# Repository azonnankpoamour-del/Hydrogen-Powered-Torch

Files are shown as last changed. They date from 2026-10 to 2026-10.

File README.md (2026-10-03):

# 🔥 Conception et réalisation d’un chalumeau à hydrogène alimenté par énergie solaire

Prototype du chalumeau

## 📌 Présentation du projet

Ce projet porte sur la **conception, le dimensionnement, la réalisation et l’expérimentation d’un chalumeau oxyhydrogène** utilisant un mélange gazeux HHO produit par **électrolyse de l’eau**.

Le système a été développé comme une alternative aux chalumeaux conventionnels utilisant des combustibles fossiles tels que l’acétylène.

L’objectif était de réaliser un prototype capable de produire son combustible à la demande et pouvant être utilisé pour des opérations de **chauffage, brasage, soudage et découpe de tôles fines**, tout en étant alimenté par une **source d’énergie solaire**.

Ce projet a été réalisé dans le cadre de mon projet de fin de formation en **Licence professionnelle – Équipements Motorisés** à l’ENSGEP / UNSTIM.

---

## 🎯 Objectifs

- Concevoir un système de chalumeau fonctionnant avec de l’hydrogène produit par électrolyse.
- Dimensionner le débit de gaz nécessaire au fonctionnement du chalumeau.
- Concevoir et intégrer un **générateur HHO de type Drycell**.
- Dimensionner l’alimentation électrique du système.
- Intégrer une alimentation photovoltaïque permettant d’améliorer l’autonomie énergétique du prototype.
- Concevoir mécaniquement l’ensemble du dispositif sous **SolidWorks**.
- Comparer différentes solutions électrolytiques.
- Réaliser et assembler le prototype.
- Effectuer des essais expérimentaux de production de gaz et de fonctionnement du chalumeau.
- Intégrer les dispositifs nécessaires à la sécurité du système.

---

## ⚙️ Principe de fonctionnement

Le fonctionnement du dispositif repose sur l’**électrolyse de l’eau**.

Sous l’action d’un courant électrique et en présence d’un électrolyte, l’eau est dissociée afin de produire du dihydrogène et du dioxygène :

**2 H₂O (l) → 2 H₂ (g) + O₂ (g)**

Le mélange gazeux produit par le générateur HHO est ensuite acheminé vers le chalumeau.

Le système comporte notamment un réservoir de solution électrolytique, une pompe de circulation, un générateur HHO-Drycell, un séparateur eau-gaz, les éléments de sécurité et le bec du chalumeau.

L’énergie nécessaire au fonctionnement du système est fournie par une batterie alimentée par un panneau photovoltaïque.

---

## 🧩 Architecture du système

Les principaux composants utilisés sont :

| Composant | Fonction |
|---|---|
| Générateur HHO – Drycell | Production du mélange gazeux HHO par électrolyse |
| Réservoir | Stockage de la solution électrolytique |
| Pompe de circulation | Circulation de la solution dans le système |
| Séparateur eau-gaz | Séparation du gaz produit et de la solution |
| Cartouche filtrante | Filtration de l’eau |
| Batterie LiFePO₄ 24 V – 10 Ah | Stockage de l’énergie électrique |
| Panneau photovoltaïque 355–375 W | Production d’énergie électrique |
| Régulateur solaire 40 A | Gestion de la charge de la batterie |
| Bec de chalumeau | Contrôle et orientation de la flamme |
| Tuyauterie et raccords | Circulation du gaz et de la solution |
| Dispositif anti-retour de flamme | Protection du circuit HHO |

---

## ☀️ Alimentation solaire

Schéma alimentation solaire

Le prototype a été conçu pour fonctionner avec une alimentation photovoltaïque.

### Caractéristiques principales

- **Panneau photovoltaïque : 355–375 W**
- **Batterie : LiFePO₄ 24 V – 10 Ah**
- **Énergie stockée : 240 Wh**
- **Régulateur de charge : 40 A**
- **Consommation théorique du Drycell : ≈ 120 W**
- **Autonomie théorique sur batterie : ≈ 2 h**

Cette architecture permet de réduire la dépendance à une alimentation électrique conventionnelle et apporte une autonomie énergétique au dispositif.

---

## 📐 Dimensionnement du débit d’hydrogène

Le dimensionnement a été réalisé pour permettre le travail sur une **tôle d’environ 0,8 mm d’épaisseur**.

En prenant comme référence un chalumeau oxyacétylénique :

- débit d’acétylène retenu : **250 mL/min**
- débit équivalent théorique d’hydrogène : **≈ 625 mL/min**
- plage de fonctionnement estimée : **600 à 750 mL/min de H₂**

Le dimensionnement théorique a donc retenu un débit cible d’environ :

**Q(H₂) = 625 mL/min**

---

## ⚡ Dimensionnement électrique

La production d’hydrogène a été dimensionnée à partir de la loi de Faraday.

Pour un débit cible de **625 mL/min**, le dimensionnement théorique conduit à un courant d’environ :

**I ≈ 60 A**

Avec une tension de cellule de l’ordre de **2 V**, la puissance théorique absorbée par le générateur est d’environ :

**P ≈ 120 W**

---

## 🧪 Étude expérimentale des électrolytes

Plusieurs solutions électrolytiques ont été étudiées expérimentalement afin d’analyser leur influence sur la production de gaz.

### Solutions testées

- Eau + bicarbonate de sodium (**NaHCO₃**)
- Eau de mer
- Eau + hydroxyde de potassium (**KOH**)

Le débit de gaz a été évalué expérimentalement par la **méthode du déplacement d’eau**.

### Résultats

| Solution | Débit expérimental |
|---|---:|
| NaHCO₃ | ≈ 1,0 L/min |
| Eau de mer | ≈ 0,7 L/min |
| KOH | ≈ 1,4 à 1,6 L/min |

Les essais ont montré que le **KOH présentait les meilleures performances** parmi les solutions étudiées.

L'étude de l'influence de la concentration a également montré un optimum expérimental autour de **6 %**, avec un débit pouvant atteindre environ **1,6 L/min avec le KOH**.

---

## 🖥️ Conception mécanique – CAO

### Générateur HHO

CAO générateur HHO

Le générateur HHO de type **Drycell** constitue l’un des éléments centraux du dispositif.

La conception mécanique a permis de définir l’organisation et l’intégration des différents composants nécessaires à la production et à la circulation du gaz.

### Assemblage du système

CAO système complet

L’ensemble du système a été modélisé sous **SolidWorks** afin d’étudier l’intégration des différents composants avant la réalisation du prototype.

Cette étape a notamment permis de travailler sur :

- la conception des pièces ;
- l’assemblage mécanique ;
- le positionnement des composants ;
- l’encombrement du système ;
- l’intégration du Drycell ;
- le passage des tuyauteries et connexions.

---

## 🔧 Réalisation du prototype

Prototype du chalumeau

Après la phase de conception et de dimensionnement, les différents composants ont été assemblés afin d'obtenir un prototype fonctionnel.

Le système comprend la chaîne :

**Énergie solaire → Batterie → Générateur HHO → Production HHO → Séparation / sécurité → Chalumeau → Flamme**

Le gaz est ainsi produit au fur et à mesure des besoins du système.

---

## 🔥 Essais et résultats

Les essais réalisés ont permis de valider le principe de fonctionnement du prototype.

### Principaux résultats

- Production effective de gaz HHO par électrolyse.
- Obtention d’une flamme stable au niveau du chalumeau.
- Débit expérimental supérieur au besoin théorique de **600–750 mL/min** avec certaines solutions électrolytiques.
- Meilleure performance obtenue avec le **KOH**.
- Débit maximal expérimental de l’ordre de **1,4 à 1,6 L/min** avec le KOH.
- Utilisation prévue pour le chauffage, le brasage, le soudage et le travail sur des tôles fines jusqu’à environ **0,8 mm**.
- Fonctionnement avec une alimentation photovoltaïque.

La littérature et le dimensionnement du projet situent la température d’une flamme oxyhydrogène à des valeurs pouvant approcher **2800 à 3300 °C** selon les conditions de fonctionnement.

> **Remarque :** la température exacte de la flamme du prototype n’a pas été mesurée expérimentalement, faute d’instrumentation adaptée. Elle ne doit donc pas être interprétée comme une température directement mesurée sur le prototype.

---

## 🛡️ Sécurité

La manipulation de l’hydrogène nécessite une attention particulière.

Plusieurs dispositions ont été prises en compte dans le projet :

- production du gaz en fonction des besoins ;
- limitation du stockage de gaz ;
- utilisation d’un dispositif anti-retour de flamme ;
- contrôle de l’étanchéité des raccords et tuyauteries ;
- vérification régulière de la cellule électrolytique ;
- éloignement des sources d’étincelles pendant les opérations de maintenance ;
- utilisation obligatoire des équipements de protection individuelle.

**EPI recommandés :**
- lunettes de protection ;
- gants de protection ;
- vêtements et équipements adaptés aux opérations de soudage.

---

## 💰 Étude économique

Le coût total estimé pour la fabrication du prototype est de :

### **637 000 XOF**

Ce montant comprend notamment :

- le générateur HHO ;
- les accessoires de circulation d’eau et de gaz ;
- le câblage ;
- le panneau photovoltaïque ;
- le régulateur solaire ;
- la batterie LiFePO₄ ;
- le bec du chalumeau ;
- le transport et les accessoires nécessaires au montage.

L’utilisation de l’énergie solaire permet par ailleurs de réduire le coût électrique associé au fonctionnement du système.

---

## 🚀 Perspectives d’amélioration

Plusieurs améliorations ont été identifiées :

- optimisation du rendement du générateur HHO ;
- optimisation de la concentration de l’électrolyte ;
- amélioration de la conception des électrodes ;
- instrumentation du système pour mesurer précisément température, pression et débit ;
- intégration de capteurs de température et de gaz ;
- automatisation de la régulation avec un microcontrôleur ou un automate ;
- mise en place d’une protection contre la surchauffe et les surtensions ;
- poursuite des recherches sur l’utilisation de l’eau de mer dans un contexte maritime ;
- amélioration de la compacité et de la portabilité du dispositif.

---

## 🧠 Compétences mobilisées

Ce projet m’a permis de mettre en œuvre des compétences multidisciplinaires en :

**Conception mécanique**
- CAO sous SolidWorks
- conception de pièces et assemblages
- intégration mécanique
- prototypage

**Dimensionnement**
- calcul énergétique
- dimensionnement électrique
- dimensionnement d’un générateur HHO
- dimensionnement d’une alimentation photovoltaïque

**Expérimentation**
- électrolyse de l’eau
- étude comparative d’électrolytes
- mesure de débit par déplacement d’eau
- analyse et interprétation de résultats expérimentaux

**Énergie**
- hydrogène
- énergie solaire photovoltaïque
- batterie LiFePO₄
- gestion énergétique

**Gestion de projet**
- étude du besoin
- conception
- dimensionnement
- réalisation
- essais
- analyse économique
- amélioration continue

---

## 📄 Documentation

Pour aller plus loin, la documentation complète du projet est disponible directement dans ce dépôt :

- 📘 [Consulter le rapport complet du projet](Rapport-Projet-Chalumeau-Hydrogene.pdf)
- 📗 [Consulter le manuel d'utilisation](Manuel-Utilisation-Chalumeau-Hydrogene.pdf)

Le rapport présente notamment le **dimensionnement**, la **conception mécanique**, les **essais expérimentaux**, l'**étude énergétique** et l'**étude économique** du prototype.

Le manuel présente le **principe de fonctionnement**, les différents composants, la **mise en service**, les consignes de **sécurité**, l'entretien et le dépannage.

Ces documents présentent le dimensionnement, la conception, les résultats expérimentaux, les procédures d’utilisation ainsi que les recommandations de sécurité.

## 🧩 Fichiers CAO

Le modèle 3D du générateur HHO de type **Drycell** est disponible dans deux formats :

- ⚙️ [Fichier source SolidWorks (.SLDPRT)](Generateur-HHO-Drycell.SLDPRT)
- 🧊 [Modèle 3D STL (.STL)](Generateur-HHO-Drycell.STL)

La modélisation CAO a été réalisée sous **SolidWorks** dans le cadre de la conception du système de production HHO.

---

## 👤 Auteur

**Amour Tamègnon AZONNANKPO**

Projet de fin de formation – Licence professionnelle  
**Génie Mécanique-Équipements Motorisés**

École Nationale Supérieure de Génie Énergétique et Procédés (**ENSGEP**)  
Université Nationale des Sciences, Technologies, Ingénierie et Mathématiques (**UNSTIM**)

Année académique : **2024–2025**

---

## ⚠️ Avertissement

Ce dépôt présente un projet académique et expérimental.

L’hydrogène et les mélanges hydrogène/oxygène présentent des risques importants d’incendie et d’explosion. Les informations contenues dans ce dépôt sont fournies à des fins de présentation technique et pédagogique et ne constituent pas des instructions permettant de reproduire le dispositif sans équipements, procédures de sécurité et encadrement appropriés.

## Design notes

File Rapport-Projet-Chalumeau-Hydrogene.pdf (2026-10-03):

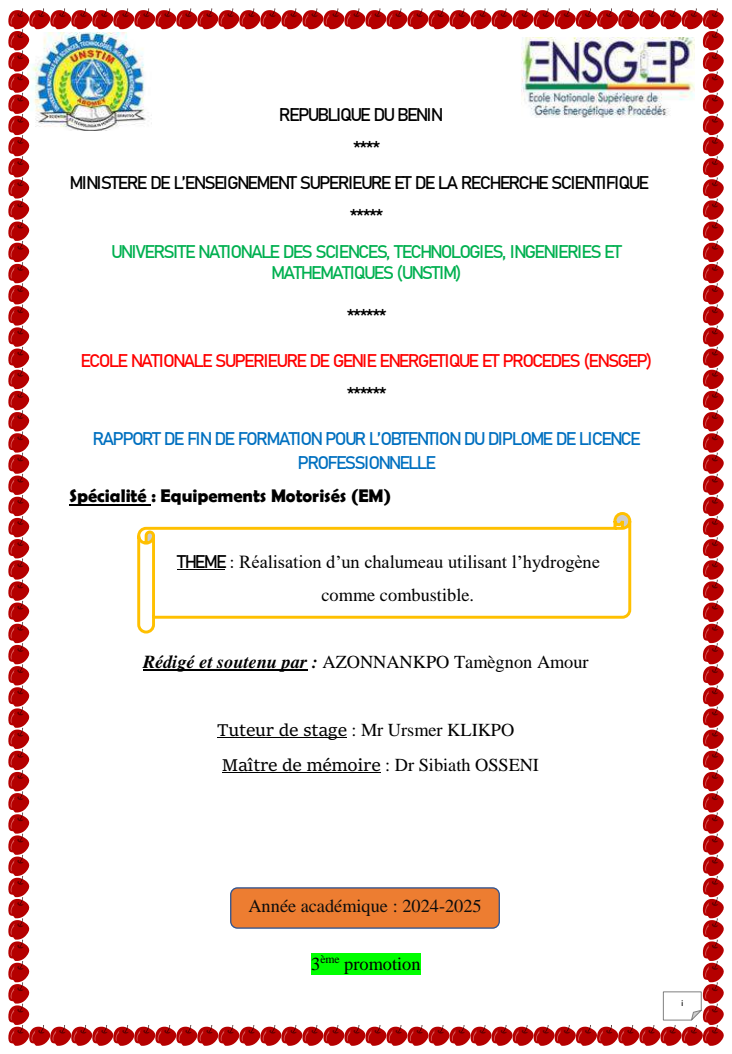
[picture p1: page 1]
Année académique : 2024-2025; MATHEMATIQUES (UNSTIM); PROFESSIONNELLE; comme combustible.; ème promotion

REPUBLIQUE DU BENIN

MINISTERE DE L’ENSEIGNEMENT SUPERIEURE ET DE LA RECHERCHE SCIENTIFIQUE

UNIVERSITE NATIONALE DES SCIENCES, TECHNOLOGIES, INGENIERIES ET

ECOLE NATIONALE SUPERIEURE DE GENIE ENERGETIQUE ET PROCEDES (ENSGEP)

RAPPORT DE FIN DE FORMATION POUR L’OBTENTION DU DIPLOME DE LICENCE

Spécialité : Equipements Motorisés (EM)

THEME : Réalisation d’un chalumeau utilisant l’hydrogène

Rédigé et soutenu par : AZONNANKPO Tamègnon Amour

Tuteur de stage : Mr Ursmer KLIKPO

Maître de mémoire : Dr Sibiath OSSENI

ii
Réalisation d’un chalumeau utilisant l’hydrogène comme combustible

## FICHE DE CERTIFICATION D’ENCADREMENT

Je soussigné, Sibiath OSSENI, Docteur en Génie Energétique et enseignante à l’Université Nationale des Sciences, Technologies ; Ingénieries et Mathématiques d’Abomey, certifie que ce travail effectué par AZONNANKPO Tamègnon Amour est original et n’a jamais été présenté pour l’obtention de quelconque grade universitaire que ce soit.

Date : |

Signature

iii

## DEDICACE

Je dédie ce modeste travail :

À Dieu Tout-Puissant, qui nous a protégés jusqu’à aujourd’hui ;
À mes chers parents, pour leur amour, leur soutien indéfectible et les nombreux sacrifices qui m'ont permis de poursuivre mes études ;
À mes enseignants et mentors, pour leur dévouement, leur patience et les précieuses connaissances qu'ils m'ont transmises tout au long de mon parcours académique ;
À mes camarades, pour leur esprit de collaboration, leurs encouragements et leur amitié tout au long de cette aventure ;
Enfin, à tous ceux qui croient en l'importance des Equipements Motorisés pour le développement technologique et durable.

iv

## REMERCIEMENTS

En premier lieu, je rends gloire et honneur à Dieu le Père Tout-Puissant pour sa grâce qui m’a accompagné tout au long de ma vie. Cette œuvre est le fruit de l’effort matériel, physique et intellectuel de plusieurs personnes. Au terme de son édification, qu’il me soit permis d’exprimer mes gratitudes et mes sincères remerciements à tous ceux qui, d’une façon ou d’une autre, ont contribué à la réussite et à la rédaction de ce mémoire.

Ainsi, mes sincères remerciements vont à l’endroit de :

Pr Antonin KANFON, Directeur actuel de l’ENSGEP, pour son accompagnement, son soutien moral, ses multiples conseils, ses orientations et sa disponibilité malgré ses occupations professionnelles et personnelles ; Dr Jean Louis FANNOU, ancien directeur de l’ENSGEP pour tout le travail effectué,
Dr Sibiath OSSENI, pour son encadrement sans faille et ses précieux conseils ; Dr Miguel ADANKPO, pour son encadrement et ses précieux conseils sur mon projet de RCHC
Tous les enseignants et membres de l’administration de l’ENSGEP, pour leurs enseignements enrichissants, les efforts qu’ils ont déployés afin de m’assurer une formation actualisée et pour m’avoir permis de travailler dans de bonnes conditions;
M. Ursmer KLIKPO mon tuteur de stage, Lieutenant mécanicien de 1ère classe et Chef du Service Engins Flottants (SEF), pour son accueil chaleureux, son suivi attentif, ses enseignements, ses précieux conseils, ses recommandations et sa disponibilité à la salle machine ;
Tous les chefs mécaniciens (officiers et graisseurs) des remorqueurs et des pilotines, pour tous les travaux effectués ensemble, l’apprentissage et leurs précieux conseils ;
Tous les patrons de vedette, tous les capitaines de remorqueurs et tous les commandants pilotes, pour leur disponibilité, leurs conseils et tout le travail effectué ensemble ;
À tous les équipages du PAC, ce fut un honneur de travailler ensemble ;; Vous, membres du jury, qui avez accepté de prendre le temps et la responsabilité d’apprécier ce travail malgré vos multiples occupations ;
À tous mes aînés qui m’ont aidé dans la rédaction de ce document.

v

## TABLE DES MATIERES

2.1.1 MESURES DE SECURITES A BORD DE LA PILOTINE ET DES

vi

CHAPITRE 3 : REALISATION D’UN CHALUMEAU UTILISANT

3.1 | GENERALITES SUR LA REALISATION D’UN CHALUMEAU
3.1.3 | UTILISATION D’UN CHALUMEAU A HYDROGENE PAR

### 3.1.3.1 AVANTAGES ET INCONVENIENTS D’UN CHALUMEAU A

3.1.4 APPLICATION DU CHALUMEAU A HYDROGENE SUR LES NAVIRES POUR LES TRAVAUX EN MER (CAS DES REMORQUEURS DU

3.2.1 | LES PRINCIPAUX ELEMENTS DU CHALUMEAU OXYHYDRIQUE
| 35
3.2.2 | DIMENSIONNEMENT DU CHALUMEAU OXYHYDROGENE....... 39
3.2.4 | ETAPES DE LA REALISATION DU CHALUMEAU A HYDROGENE
| 43

vii

## LISTE DES SIGLES ET ABREVIATIONS

ENSGEP | Ecole Nationale Supérieure de Génie Energétique et Procédés
EM | Equipements Motorisés
SGE | Secrétaire Générale d’Entité de l’ENSGEP
UNSTIM | Université Nationale des Sciences Technologies, Ingénierie et Mathématiques
RCHC | Réalisation d’un Chalumeau utilisant l’hydrogène comme combustible
PAC | Port Autonome de Cotonou
GE | Groupe Electrogène
MP | Moteur Propulseur
Td | Tribord
Bd | Bâbord
ml | Millilitre
mm | Millimètre
g | gramme
J | Joule
cm | Centimètre
°C | Degré Celsius
MJ | Mégajoule
KJ | Kilojoule
Wh | Wattheure
A | Ampère
V | Volt
∆ | Delta T

viii

## LISTE DES TABLEAUX

Tableau 5: Récapitulatif des avantages et inconvénients des chalumeaux oxhydriques

Tableau 13 : Détails sur le système d’alimentation du chalumeau à hydrogène…64

ix

## LISTE DES FIGURES

Figure 23 : Drycell | 47.

Figure 26 : Conception assistée par ordinateur du chalumeau à hydrogène (SolidWorks)..55.

x

## RESUME

L’hydrogène s’impose aujourd’hui comme une solution énergétique propre, sûre et efficace pour remplacer les combustibles fossiles dans les applications industrielles.

A cet effet, l’étude a porté sur la réalisation d’un chalumeau fonctionnant à l’hydrogène et utilisant une source d’énergie solaire, une alternative aux chalumeaux classiques à butane ou à acétylène, plus polluants et dangereux.

Dans ce projet, il a d’abord été nécessaire de concevoir, dimensionner puis assembler un chalumeau oxyhydrogène fonctionnel. Le principe repose sur l’électrolyse de l’eau, permettant de générer un mélange gazeux d’hydrogène et d’oxygène (HHO) servant de combustible à une flamme maîtrisée. L’ensemble de l’étude a intégré une sélection des matériaux, la mise en place d’un système de sécurité adapté à l’hydrogène, ainsi que plusieurs essais de performance et de fiabilité.

Les résultats expérimentaux ont démontré l’efficacité thermique du chalumeau, avec une température de flamme atteignant jusqu’à 3300 °C, comparable à celle de l’oxycoupage classique. Le système a également présenté un fonctionnement stable et sécurisé avec un débit d’hydrogène assez élevé obtenu grâce à une électrolyse optimisée, permettant une alimentation continue de la flamme.

Le coût total du projet est estimé à 637 000 XOF, hors main-d’œuvre. Ce montant couvre l’achat des matériels et l’acquisition des dispositifs techniques nécessaires au montage.

Ce chalumeau constitue une avancée technologique viable, conjuguant sécurité, performance, autonomie énergétique et réduction des impacts environnementaux.

Mots-clés : hydrogène, chalumeau, combustion propre, électrolyse, énergie renouvelable, soudage

xi

ABSTRACT

Hydrogen is emerging today as a clean, safe, and efficient energy solution to replace fossil fuels in industrial applications.

This study focused on the development of a hydrogen-powered torch using a solar energy source, offering an alternative to conventional butane or acetylene torches, which are more polluting and hazardous.

The project involved designing, sizing, and assembling a functional oxyhydrogen torch. The operating principle is based on water electrolysis, which generates a gaseous mixture of hydrogen and oxygen (HHO) used as fuel for a controlled flame. The study included material selection, the implementation of a safety system adapted to hydrogen, and several performance and reliability tests.

Experimental results demonstrated the thermal efficiency of the torch, with a flame temperature reaching up to 3300 °C, comparable to that of conventional oxy-cutting systems. The system also operated in a stable and safe manner, with a relatively high hydrogen flow rate achieved through optimized electrolysis, enabling continuous flame supply.

The total cost of the project is estimated at 637,000 XOF, excluding labor. This amount covers the purchase of materials and the acquisition of the technical components required for assembly.

This torch represents a viable technological advancement, combining safety, performance, energy autonomy, and reduced environmental impact.

Keywords: hydrogen, torch, clean combustion, electrolysis, renewable energy, welding

1

INTRODUCTION GENERALE

L’énergie est un élément déterminant et indispensable pour l’économie d’un pays. Elle est directement liée à son développement, cela est valable pour les pays développés (industrialisés) que pour les pays émergents.

Les combustibles d’origine fossile contribuent massivement au réchauffement climatique de la terre par "effet de serre" dû au dégagement du dioxyde de carbone par leur combustion dans l'atmosphère. La prise de conscience environnementale à travers les accords internationaux tel que l’accord de Kyoto a poussé les pays industrialisés à réduire leur rejet de gaz à effets de serre : l'Allemagne est parvenue à elle seule à réduire ses rejets à 50 millions de tonnes de CO2. [1]

L’hydrogène est l’une des solutions énergétiques qui pourra répondre aux besoins actuels. Bien qu'on le trouve en abondance dans l'univers, mais combiné avec d'autres atomes : cas notamment de l'eau, du pétrole ou du gaz naturel. L’hydrogène est considéré comme un vecteur énergétique très intéressant produit essentiellement par électrolyse. Il est utilisé essentiellement dans la chimie, le raffinage ou l’industrie. A l’heure des préoccupations environnementales, l’hydrogène pourrait bien, jouer un rôle prépondérant dans le paysage énergétique futur. [2]

Le travail présenté dans ce mémoire est relatif à la « RÉALISATION D’UN CHALUMEAU UTILISANT L’HYDROGÈNE COMME COMBUSTIBLE », une solution innovante, plus sûre, plus écologique et mieux adaptée aux besoins modernes de soudage et de réparation, notamment dans les industries et à bord des vedettes et remorqueurs où la sécurité est une exigence capitale.

Ce travail sera structuré en trois grands chapitres :

Le premier chapitre présentera notre cadre de formation (ENSGEP/ABOMEY) ainsi que la structure d’accueil pour notre stage.
Le deuxième chapitre décrira le déroulement du stage ainsi que les différents travaux pratiques réalisés.
Le troisième chapitre sera consacré à l’étude approfondie du thème
« RÉALISATION D’UN CHALUMEAU UTILISANT L’HYDROGÈNE

COMME COMBUSTIBLE ».

2

## CHAPITRE 1 : CADRE INSTITUTIONNEL DU STAGE

3

INTRODUCTION

Dans le cadre de la formation pratique des étudiants, l’École Nationale Supérieure de Génie Énergétique et Procédés organise chaque année des stages en entreprise. Ces stages permettent aux étudiants d'appliquer sur le terrain les connaissances théoriques acquises durant leur cursus. C’est ainsi que j'ai effectué mon stage de fin de formation au Port Autonome de Cotonou (PAC), dans le but de renforcer mes compétences pratiques en maintenance marine et d’approfondir ma compréhension des réalités professionnelles.

### 1.1 PRESENTATION DU CADRE DE FORMATION 1.1.1 HISTORIQUE

L'École Nationale Supérieure de Génie Énergétique et Procédés (ENSGEP) constitue une composante clé de l'Université Nationale des Sciences, Technologies, Ingénierie et
Mathématiques | (UNSTIM) | d'Abomey. | Créée | par | l'Arrêté | Ministériel | N°
207/MESRS/DC/SGM/DGES/DAF/R-UNSTIM/CCJ/SA 027SGG18 en date du 18 avril 2018, elle place l'innovation et l'excellence au cœur de son contrat pluriannuel, renforçant ainsi son attractivité. L'ENSGEP se donne pour mission de former des ingénieurs et techniciens spécialisés dans les domaines des sciences et des technologies, avec un accent particulier sur le génie énergétique et les procédés, la réfrigération et la climatisation, ainsi que les équipements motorisés.

Nos ingénieurs, experts en solutions techniques dans les secteurs de l'industrie et de l’énergie, maîtrisent la conception, l'étude, le dimensionnement et la mise en œuvre des unités de production adaptées à une diversité d'activités. Quant à nos techniciens, leurs compétences leur permettent d'installer et de garantir la maintenance efficace des systèmes de réfrigération, de climatisation et des équipements motorisés. Depuis son ouverture à l'année académique 2018-2019, l'ENSGEP s'engage à assurer :

- Des formations de pointe, conduisant principalement aux diplômes d’ingénieur de conception (BAC+5) en sciences et technologies appliquées à l’énergétique et aux procédés industriels, ainsi qu’aux diplômes de licence professionnelle (BAC+3) dans les domaines du froid et de la climatisation, et des équipements motorisés.
- La recherche scientifique et technique, visant à promouvoir l'innovation technologique dans les sciences et technologies de l’énergétique et des procédés industriels.
- La formation continue, destinée à répondre aux besoins des personnels des entreprises publiques et privées, favorisant leur montée en compétences dans les domaines spécifiques sollicités.

4

### 1.1.2 DEBOUCHES POUR LES FORMATIONS A l’ENSGEP

L’ENSGEP présente trois (03) formations :

Un cycle d’ingénieur en Génie Energétique et Procédés

Débouchés : Ingénieur industriel, Chef d’usine, Ingénieur Bureau d’étude, Ingénieur conseil et commercial près des fabricants des équipements énergétiques, Ingénieur en énergies renouvelables, etc.
Un cycle de Licence professionnelle en Équipements Motorisés

Débouchés : Technicien en installation, mise en service et maintenance des

Équipements Motorisés, Électromécanicien, Technicien en Mécanique automobile, Technicien en installation et Maintenance des appareils électroménagers, Technicien en installation et Maintenance des engins de travaux publics, Technicien en installation et Maintenance des groupes électrogènes, s’installer à son propre compte.

Un cycle de Licence professionnelle en Froid et Climatisation

Débouchés : Technicien en installation, mise en service et maintenance d’installations frigorifiques près de PME et Institutions, s’installer à son propre compte les prestations de service en froid et climatisation.

### 1.1.3 CONDITIONS D’ACCES A l’ENSGEP

L’accès au cycle d’ingénieur de l’ENSGEP est réservé aux étudiants ayant fini les classes préparatoires à l’Institut Nationale des Classes Préparatoires aux Etudes d’Ingénieur (INSPEI) ou sur un test d’entrée pour ceux qui ont fait les deux ans d’année préparatoire scientifique ou sur un test d’entrée pour ceux qui ont la licence professionnelle en Energie renouvelable, Génie mécanique et productique, Génie industriel et maintenance, Energie renouvelable et maintenance des systèmes énergétiques, Physique ou tout autre diplôme équivalent.

L’accès au cycle de licence professionnelle se fait sur le classement des nouveaux bacheliers des séries C, D, E, DT/FC et DEAT par le ministère (sélection à titre de boursiers, à titre partiellement payant et à titre entièrement payant) et sur étude de dossiers (à titre entièrement payant uniquement) des anciens bacheliers des séries C, D, E, DT/FC et DEAT. L’école dispose d’un laboratoire pluridisciplinaire pour les travaux pratiques de ses étudiants et collabore avec plusieurs laboratoires et entreprises tant publics que privés afin de renforcer la professionnalisation de ses offres de formation.

5

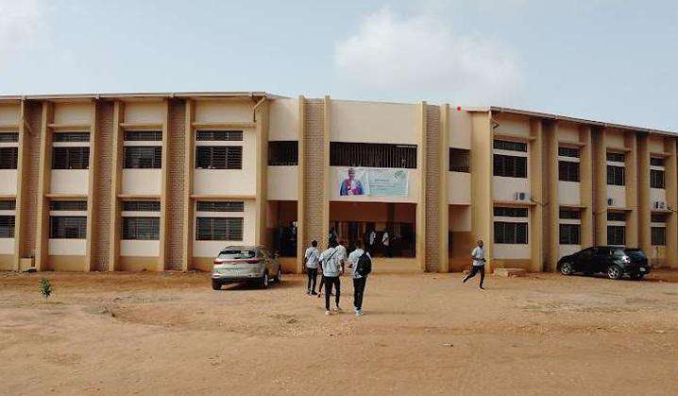
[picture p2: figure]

Figure 1 : Photographie montrant la devanture du site provisoire de l’ENSGEP [3]

### 1.1.4 LOCALISATION

L’ENSGEP est situé dans la ville d’Abomey dans le département du Zou, au Bénin. Précisément à Sogbo-Aliho en face l’école Shino Béninoise de la ville. Le site est à gauche proche de la Route Inter Etat quittant le carrefour Sogbo-Aliho pour l’Ecole Nationale des Instituteurs (ENI) d’Abomey comme l’indique la figure 2

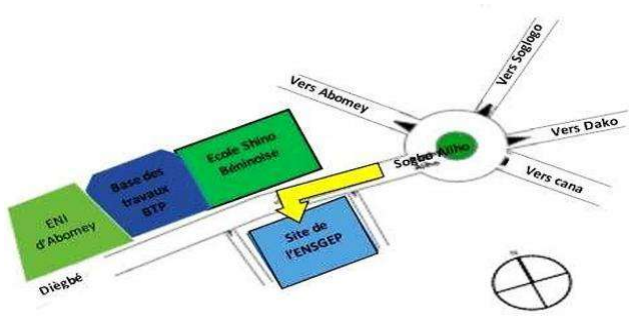
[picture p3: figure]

Figure 2 : Plan de la situation géographique de l’ENSGEP [4]

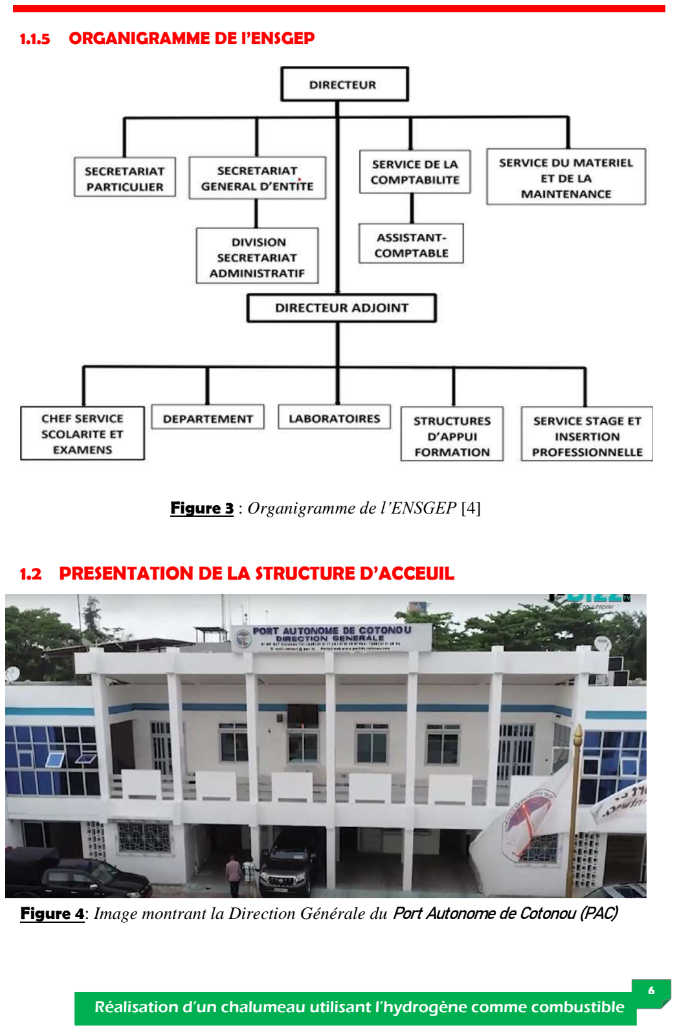
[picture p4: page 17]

6

### 1.1.5 ORGANIGRAMME DE l’ENSGEP

Figure 3 : Organigramme de l’ENSGEP [4]

## 1.2 PRESENTATION DE LA STRUCTURE D’ACCEUIL

Figure 4: Image montrant la Direction Générale du Port Autonome de Cotonou (PAC)

7

### 1.2.1 HISTORIQUE ET ORGANISATION DE L’ENTREPRISE

### - Historique du Port Autonome de Cotonou (PAC)

L’embarquement et le débarquement des marchandises s’effectuaient en deux points du littoral du Bénin (Grand-Popo à l’embouchure du Mono et Ouidah, ancien port de la traite des esclaves) par transbordement des pirogues qui assuraient la liaison entre les navires mouillants en rades foraines et le rivage avant la naissance du port autonome de Cotonou (Janin, 1964). Ainsi, la ville de Cotonou est dotée d’un wharf (passe raine métallique). La sécurité des marchandises et des personnes et la rapidité dans l’exécution des opérations a permis au site de Cotonou de supplanter celui de Grand-Popo et de Ouidah et de devenir le principal port du Dahomey. La réalisation donc d’un port moderne en eau profonde rend concrète la supériorité de Cotonou (Janin, 1964). Ce port est né pour faire face aux concurrences avec les ports du Sénégal et de la Cote d’Ivoire. Le port de Cotonou depuis ce temps est le véritable atout de développement économique car il représente 75% du trafic dahoméen (Janin, 1964). [5]

Le port représente aujourd’hui 50% de la richesse nationale du pays et fait 90% des échanges avec l’étranger d’où il est le véritable poumon de l’économie béninoise (INSAE, 2011). Il fait du commerce entre les autres pays du monde notamment l’Europe, l’Amérique Nord comme du Sud et l’Asie (PAC, 2013 et Messan, 2014). Ainsi le port de Cotonou est le port relai de la première puissance économique africaine qu’est le Nigéria et le port de transit du Niger (Messan, 2014) d’où la richesse nationale du Bénin (INSAE, 2011). [5]

### - Situation géographique du port autonome de Cotonou

Situé à la latitude 6°11’22’’ Nord, le Port de Cotonou est implanté sur une côte sablonneuse en bordure sud de la ville de Cotonou, capitale économique de la République du Bénin. Port en eau profonde à accumulation de sable, il a pour grand avantage de fournir aux navires un plan d’eau abrité, pouvant leur permettre d’effectuer des opérations commerciales et de ravitaillement dans d’excellentes conditions. Sa position géographique lui offre un travail indéniable. Cette disposition contribue à l’efficacité du Port et à la rapidité d’escale des navires. En effet, le Port Autonome de Cotonou est le débouché à la mer le plus proche, le couloir d’accès le plus rapide, le moins accidenté pour desservir l’Est des pays sans littoral tels que le Mali, le Burkina-Faso, le Niger et le Tchad.

Dans la sous- région, le Port de Cotonou est sensiblement à égale distance des ports de Lagos (Nigeria) 115Km et de Lomé (Togo) 135Km. Le port de Cotonou est le port relai et de transbordement le plus rapide vers le Nigéria. [5]

8

### 1.2.1.1 ORGANIGRAMME DU PAC

Figure 5 : Schéma montrant l’Organigramme du PAC [6]

9

### 1.2.2 LA FLOTTE DU PAC

- Service pilotine

Cette section est responsable du transport du pilote. La pilotine se rend jusqu’à la bouée d’atterrissage pour déposer le pilote à bord du navire étranger lors de son entrée. En cas de sortie, la pilotine récupère le pilote après qu’il a assisté le commandant à rejoindre la voie de départ. Cette section dispose de deux pilotines : AGBONNON et EMERGENCE.

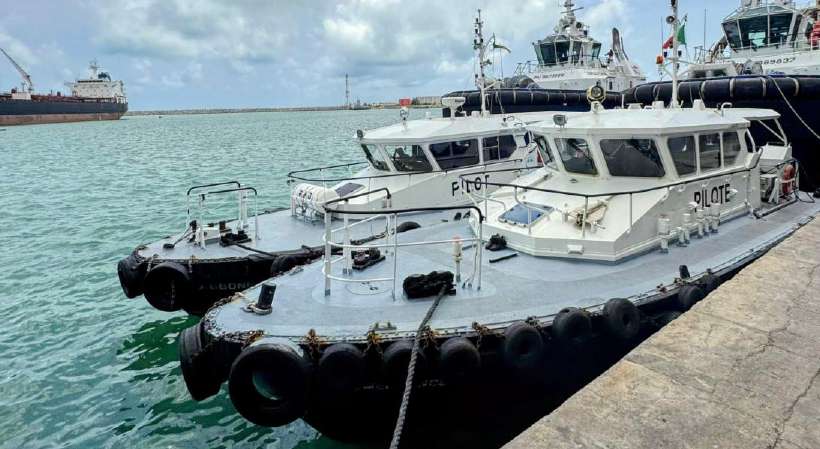
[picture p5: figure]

Figure 6 : Image montrant les deux pilotines EMERGENCE ET AGBONON

Tableau 1 : Caractéristiques des pilotines [6]

Engins | Année de construction | Longueur(m) | Largeur(m) | Tirant(m) | Puissance moteur
EMERGENCE | 2007 | 15,25 | 04,80 | 1,255 | 720Kw
AGBONNON | 2018 | 15,21 | 04,47 | 2,18 | 640Kw
- Service remorquage

La remorque est un ensemble d’éléments qui permettent de tracter un navire. Elle sert à guider, tirer, pousser les gros bateaux entrant et sortant du port. La station de remorquage du port autonome de Cotonou est équipée de trois remorqueurs à savoir : Cauris, Bio-Guerra et Amazone. La prestation est obligatoire pour les navires de plus de 100 m3 à l’entrée comme à la sortie.

Les navires citernes transportant des produits dangereux devront recourir à deux remorqueurs au moins quelle que soit leur taille.

10

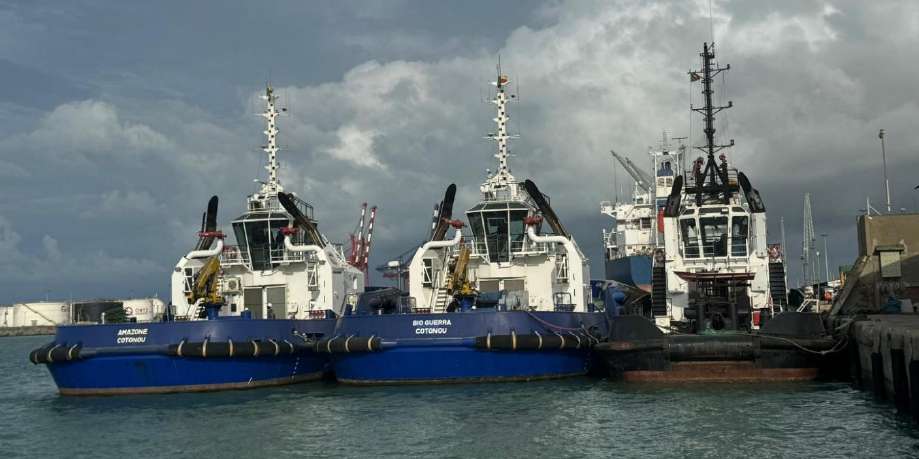
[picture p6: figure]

Figure 7 : AMAZONE, BIO-GUERRA ET CAURIS

Tableau 2 : Caractéristiques des remorqueurs [6]

Engins | Longueur(m) | Largeur(m) | Année de construction | Puissance | Jauge brute
Cauris | 29,9 | 9 | 2009 | 1305Kw x 2
Bio-Guerra | 27,60 | 12,96 | 2021 | 2525Kw x 2 | 85T
Amazone | 27,60 | 12,96 | 2021 | 2525Kw x 2 | 85T

11

## CHAPITRE 2 : DEROULEMENT DU STAGE

12

### 1.3 OBJECTIFS DU STAGE

À la fin de chaque année, l’ENSGEP organise des stages pour ses apprenants au sein de diverses structures afin de leur permettre de découvrir les réalités du monde professionnel. C’est ainsi que nous avons été affectés au Port Autonome de Cotonou (PAC), plus précisément à la Direction des Opérations Portuaires et de la Sécurité (DOPS), dans le Département de Remorquage et Engins Flottants (DREF), pour effectuer un stage de fin de formation d’une durée de trois (03) mois.

Ce stage nous a offert l’opportunité d’acquérir une expérience pratique dans la maintenance des engins flottants tels que les remorqueurs et les pilotines. Il nous a également permis de mettre en pratique les connaissances théoriques acquises durant notre formation, notamment en Technologie et Maintenance des Équipements Marins. Par ailleurs, nous avons appris à interpréter divers paramètres en salle des machines, comme la pression de carburant et du liquide de refroidissement, le démarrage des moteurs, ainsi que celui des ventilateurs d’aération tribord et bâbord. Nous avons également acquis des compétences en inspection visuelle pour détecter des pannes, ainsi qu’en manœuvre avec les capitaines et les patrons de vedette.

### 1.3.1 MESURES DE SECURITES A BORD DE LA PILOTINE ET DES REMORQUEURS 1. Respect des consignes générales

- Se conformer strictement aux règles de sécurité du bord et aux instructions du chef mécanicien.
- Connaître les plans d’urgence, les itinéraires d’évacuation et la localisation des équipements de secours.
- Signaler immédiatement toute anomalie, fuite, bruit inhabituel ou odeur suspecte.

### 2. Port des équipements de protection individuelle (EPI)

Porter en permanence les EPI requis :

- Port des gilets de sauvetage lorsqu’on est sur le pont
- Casque de sécurité
- Chaussures de sécurité antidérapantes et renforcées
- Gants adaptés aux travaux (mécaniques, thermiques, chimiques)
- Protection auditive (bouchons ou casque antibruit)
- Lunettes de protection ou visière en cas de projections
- Vêtements de travail ignifugés et résistants

### 3. Prévention des risques mécaniques

- Ne jamais intervenir sur un équipement en fonctionnement sans autorisation.
- S’assurer que les équipements sont arrêtés, débranchés et sécurisés avant toute maintenance (procédure de verrouillage / étiquetage).
- Rester vigilant à la proximité des pièces en mouvement (courroies, turbines, arbres de transmission…).

13

### 4. Surveillance et propreté des lieux

- Garder la salle machine propre, sèche et dégagée de tout déchet ou fluide.
- Nettoyer immédiatement toute fuite d’huile, de carburant ou de liquide glissant.
- Ranger les outils après usage et éviter les déversements de produits.

### 5. Sécurité incendie

- Connaître la localisation des extincteurs et du système d’extinction automatique (CO₂, brouillard d’eau).
- Ne jamais stocker de produits inflammables ou de chiffons gras à proximité des moteurs ou surfaces chaudes.
- Ne jamais fumer dans la salle machine.

### 6. Sécurité électrique

- Ne pas manipuler d’équipements électriques sans habilitation.
- Vérifier l’état des câbles et des connexions avant toute intervention.
- Toujours utiliser des gants isolants et outils spécifiques si une manipulation est nécessaire.

### 7. Comportement et vigilance

- Evitez d’être seul à la salle machine (être toujours à deux au moins)
- Toujours signaler sa position à l’un de ses collègues sur le bateau
- Ne jamais travailler seul lors d’interventions à risque sans surveillance ou moyen de communication.
- Participer activement aux exercices de sécurité et aux briefings techniques.

### 8. Réactivité en cas d’urgence

- Savoir activer l’arrêt d’urgence des machines.
- Savoir donner l’alerte et utiliser les équipements de secours.
- Connaître le plan d’évacuation de la salle machine.

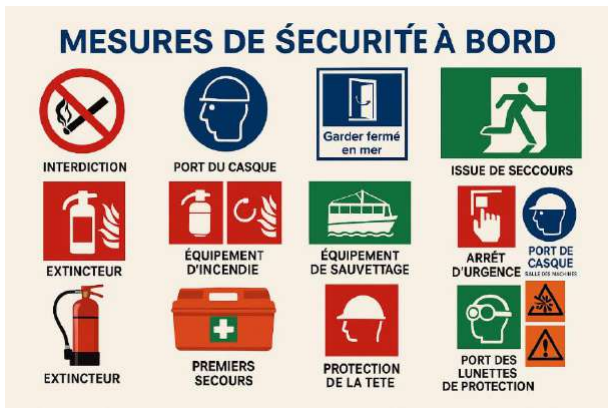
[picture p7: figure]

Figure 8: Mesures de sécurité à bord des remorqueurs et pilotines (PAC)

14

### 1.4 PRESENTATION DES TRAVAUX EFFECTUES

Pour garantir une maintenance efficace et quotidienne des engins flottants et des remorqueurs, il est essentiel de privilégier principalement les méthodes préventives, afin d’anticiper les pannes, étant donné qu’il s’agit de structures naviguant en haute mer. Les méthodes curatives sont également employées, mais restent beaucoup plus rares.

### 1.4.1 SERVICE ENGINS FLOTTANTS 1.4.1.1 LISTE DES TACHES EFFECTUEES

-Inspection visuelle des équipements de la salle des machines (MP, GE) pour détecter les signes d’usure et les fuites potentielles.

-Démontage et remplacement du capteur d’eau du MP Tribord de la pilotine AGBONNON.

-Démarrage et extinction des moteurs et générateurs : Procédures de démarrage et d’arrêt des moteurs principaux et des générateurs en cas d’appareillage et d’accostage.

-Soutage de la pilotine (Transfert de gasoil du remorqueur vers la pilotine).
- La pilotine AGBONNON a une capacité de 1800L de gasoil.

-Entretien des boîtes Égyptiennes des pilotines AGBONNON et EMERGENCE, un élément clé du système de refroidissement, pour assurer une navigation précise
- Cette opération est obligatoirement hebdomadaire.

-Opération de vidange du Moteur Propulseur Bâbord de la pilotine AGBONNON
- Elle se fait après tous les 250H de marche de l’engin.

-Changement du filtre à gasoil et du filtre à huile du MP Tribord de la pilotine AGBONNON
- Cette opération est effectuée suite à un problème de démarrage du moteur et en retour s’éteint de lui-même à une certaine température et pression.

-Contrôle des niveaux de l’huile moteur et du liquide de refroidissement des deux pilotines
- Cette opération est réalisée quotidiennement.

-Opération de vidange du GE de la pilotine AGBONNON sans remplacement de filtre à huile.
- Elle se fait après tous les 100H de marche de l’engin.

15

-Lecture de l’horamètre et interprétation pour relever les valeurs.

- Nettoyage minutieux des parois de la salle des machines et du local de climatisation pour maintenir un environnement propre et prévenir la corrosion.
- Vidange de la cale et des eaux usées
- Il faut régulièrement vidangée la cale et des eaux usées à l’aide de la pompe de cale pour prévenir l’accumulation de liquides indésirables et garantir la stabilité du navire.

### 1.4.1.2 DESCRIPTION DES ACTIVITES PRINCIPALES :

1- Ronde journalière
La ronde journalière consiste à une vérification et une inspection minutieuse de certains équipements de la salle machine que sont :
Tableau 3: Ronde journalière PILOTINE. MACHINE
- Inspection générale des espaces ;
- Examiner le moteur (Bd et Td);
- Vérifier le niveau d'huile (Bd et Td);
- Examen quotidien du moteur (Bd et Td);
- Examen du niveau d'huile du générateur d'impulsions de vanne SOS;
- Purge de l'eau des réservoirs de carburant;
- Purge du séparateur d'eau (Bd et Td);
- Purge du séparateur;
- Contrôle quotidien de l'espace technique (salle machines);
- Fournir les valeurs des compteurs et consommation calculer à déposer dans la boite aux lettres;

ELECTRICITE
- Examen quotidien du système ICAF;
- Examiner le système fixe d'extinction d'incendie.

2- Démarrage et extinction des moteurs et générateurs :
Procédures de démarrage et d’arrêt des moteurs principaux et des générateurs en cas d’appareillage et d’accostage.

### A l’appareillage :

1-Débrancher le courant de quai.
2-Descendre rapidement à la machine pour inspection et vérification visuelle. 3-Démarrer le GE (Appui long sur le bouton Start jusqu’à ce que ça prenne). 4-Démarrer les moteurs Tribord et Bâbord, l’un après l’autre en suivant la procédure de démarrage habituelle.

16

5-Descendre à la cabine pour armer le GE ;
6-Mettre en marche le ventilateur de la salle machine.
NB : Le démarrage des MP et du GE peut se faire depuis la machine ou à la passerelle.

### A l’accostage :

1-Ouvrir la porte de la salle machine
2-Eteindre le GE en suivant les procédures d’arrêt
3-Eteindre les MP en suivant les procédures d’arrêt habituelles
4-Brancher le courant de quai et aller à la cabine pour armer.
5-Mettre le ventilateur d’aération des machines en marche
6-Mettre en marche la pompe de cale pour vider l’eau de mer si nécessaire.
NB : L’arrêt des MP et du GE peut se faire depuis la machine ou à la passerelle.

3- Opération de vidange du Moteur Propulseur Bâbord de la pilotine AGBONNON
Voici les étapes à suivre :
-Préparation : Placer un récipient adapté sous la sortie de la vanne de vidange pour recueillir l'huile usagée.
-Ouvrir la vanne reliée au carter inférieur du Moteur Propulseur Bâbord.
-Laisser l'huile s'écouler jusqu'à ce que la majeure partie de l'huile soit évacuée. -Fermer la vanne : Une fois l'huile évacuée, fermer la vanne en s'assurant qu'il soit bien fermé pour éviter toute fuite.
-Démonter l’ancien filtre à huile avec la clé filtre.
-Préparer le nouveau filtre : Appliquer de l’huile neuve sur la surface du filtre et mettre environ 3,5L dans le filtre avant de le poser et serrer
-Remplissage avec de l'huile neuve : Ouvrir le bouchon situé sur la surface supérieure du moteur et remplir de l’huile neuve dans le moteur (environ 20L).
-Attendre que l’huile se pose dans le carter inférieure du moteur et utiliser, la jauge pour vérifier le niveau d'huile et rajouter de l'huile si nécessaire.
-Vérification finale : Démarrage du moteur pour permettre à l'huile de circuler. -Vérification du niveau d'huile après quelques minutes de fonctionnement et ajouter l'huile si le niveau est trop bas.

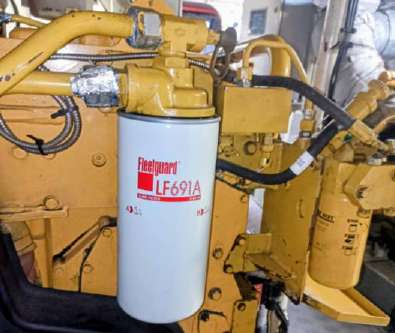
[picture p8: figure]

Figure 9: Vue du MP tribord et du filtre à huile de la pilotine AGBONNON

17

4- Entretien des boîtes Égyptiennes des pilotines AGBONNON et EMERGENCE, un élément clé du système de refroidissement, pour assurer une navigation précise.
Voici les étapes à suivre :
1-Fermer délicatement les vannes d’eau de mer des boites égyptiennes.
2-Prendre une clé et démonter le couvercle supérieur de la boite égyptienne
3-Enlever la crépine d’eau de mer
4-Prendre l’eau savonneuse et de la brosse métallique pour bien nettoyer les impuretés de la crépine et rincer là avec de l’eau propre.
5-Ramener la crépine nettoyée et remonter là à son emplacement
6-Remonter le couvercle de la boite égyptienne et ouvrir la vanne pour voir s’il y a fuite d’eau de mer.
7-Après vérification, bien serrer le couvercle de la boite égyptienne et ouvrir la vanne. NB : Le même processus est répété pour les moteurs Tribord et Bâbord des pilotines AGBONNON et EMERGENCE.

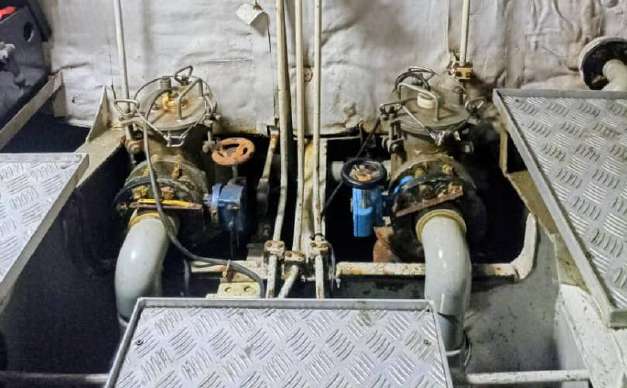
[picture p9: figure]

Figure 10: Vue de face des boites égyptienne de la pilotine AGBONNON

5- Opération de vidange du GE de la pilotine AGBONNON sans remplacement de filtre à huile.
1- Préparation : Placer un récipient adapté sous la sortie du raccord de vidange pour recueillir l'huile usagée
2- Laisser le GE refroidit et ouvrir le bouchon d’huile du carter inférieure du moteur. 3- Laisser l'huile s'écouler jusqu'à ce que la majeure partie de l'huile soit évacuée. 4-Fermer le bouchon de vidange et remettre le raccord à sa place.
5-Ouvrir le bouchon de remplissage d’huile du GE et remplir l’huile neuve dans le GE (Environ 4L).
6-Retirer la jauge pour voir le niveau de l’huile dans le carter et compléter si possible. 7- Vérification finale : Démarrage du GE pour permettre à l'huile de circuler. Vérification du niveau d'huile après quelques minutes de fonctionnement et ajouter l'huile si le niveau est trop bas.

18

6- Vérification du niveau de l’huile des MP et des réducteurs
Cette tâche est journalière et obligatoire. Elle se fait tous les matins avant l’utilisation de l’engin en manœuvre. Il s’agit de :
- Vérifier d’abord si le moteur est bien à l’arrêt depuis au moins 10min
- Faire sortir la jauge de niveau du réducteur et l’essuyer avec un torchon
- Remettre la jauge de niveau dans le réducteur et le fait sortir à nouveau
- Regarder avec précision le niveau de l’huile (il doit être situé entre le repère mini et le repère maxi marqués sur la jauge)

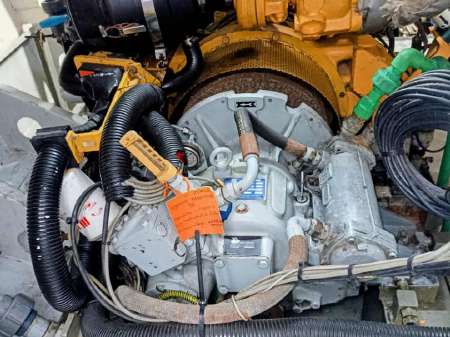
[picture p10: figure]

Figure 11 : Vue des réducteurs Bâbord et Tribord de la pilotine AGBONNON

7- Vérification des niveaux du liquide de refroidissement des MP et des GE
Cette tâche est journalière et obligatoire pour éviter tout problème de surchauffe ou de coupure du moteur en pleine manœuvre. Elle se fait tous les matins avant l’utilisation de l’engin. Il s’agit de :
- Regarder avec attention et précision le niveau du liquide de refroidissement dans le bocal du liquide de refroidissement du moteur.
- Vérifier si le niveau est bon (c’est-à-dire qu’il doit se situer entre les repères mini et maxi marqués sur le bocal).
NB : Pour la pilotine EMERGENCE, il faut continuer l’exercice en vérifiant le niveau de liquide de refroidissement dans la caisse d’expansion du MP lui-même. Pour cela :
- S’assurer que le moteur est à l’arrêt et qu’il est bien froid ;
- Ouvrir avec délicatesse le bouchon de la caisse d’expansion de l’MP ;
- Vérifier le niveau en mettant votre doigt dedans et voir si effectivement cela touche le liquide ;
- Si oui, refermer le bouchon de la caisse d’expansion.

19

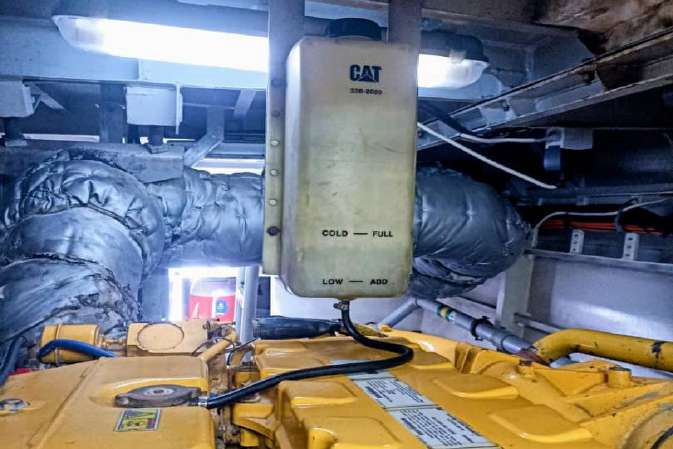
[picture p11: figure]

Figure 12 : Bocal et caisse d’expansion du moteur Tribord de AGBONNON

8- Vidange de l’eau de cale de l’engin
Cette opération est obligatoire lorsqu’on constate immédiatement qu’il assez d’eau de mer dans la cale de la salle machine parce que le premier ennemi du bateau est l’entrée de l’eau de mer à l’intérieur du bateau. Pour cela, il faut :
- Descendre à la cabine de l’engin pour disposer les vannes comme indiqué dans la procédure ;
- Actionner la pompe de cale pour expulser l’eau à l’extérieur de l’engin ;
- Retourner sur le pont de l’engin pour vérifier si l’eau de cale sort effectivement ;
- Une fois l’opération terminée, arrêter la pompe de cale te fermer les vannes.

Figure 13 : Image montrant la pompe d’assèchement de la salle machine

20

### 1.4.2 SERVICE REMORQUAGE 1.4.2.1 DESCRIPTION DES ACTIVITES PRINCIPALES :

9- Ronde Journalière
Chaque journée pour moi débutait par une ronde d'inspection rigoureuse des équipements. Lors de ces vérifications systématiques, les niveaux de liquide de refroidissement, d'huile moteur, le remplissage des réservoirs de gasoil ainsi que l'état des crépines étaient contrôlés scrupuleusement. Cette routine préventive permet d'identifier rapidement toute anomalie et d'éviter ainsi les pannes majeures. L'image ci-dessous présente la ronde journalière du remorqueur AMAZONE.

Tableau 4: Ronde journalière machine AMAZONE. MACHINE
- Inspection générale des espaces;
- Examen quotidien du système ICAF;
- Examen quotidien du moteur (Bd et Td);
- Examen du propulseur AZIMUTAL (Bd et Td);
- Contrôle quotidiens du système de commande de propulseur;
- Examen du niveau d'huile du générateur d'impulsions de vanne SOS:
- Purge de l'eau des réservoirs de combustible;
- Examen du moteur thermique du GE (Bd et Td);
- Examen quotidien du treuil d'ancre (Bd et Td):
- Examen du système de freinage de treuil de remorquage avant;
- Examen du système hydraulique;
- Examen de la pression et de la purge d'eau sur le circuit d'air comprimé;
. Purge des condensats sur le compresseur d'air;
. Contrôle quotidien de l'espace technique (salle machines);
- Valeurs des compteurs et des consommations à déposer dans la boite aux lettres:

ELECTRICITE
. Contrôle quotidien de l'espace technique (local électrique); . Examiner le détecteur de gaz quotidien;
- Examen de la tuyauterie du système de freinage (Bd et Td); . Contrôle quotidien de la lampe UV;
. Examen du chauffe-eau;

10- Démarrage et extinction des moteurs et générateurs : Procédures de démarrage et d’arrêt des moteurs principaux et des générateurs avant et après les manœuvres, en veillant à respecter la séquence correcte pour éviter les surcharges et assurer une transition fluide.

21

Préparation: Vérification initiale avant de démarrer les moteurs ou les générateurs. Cela inclut la vérification des niveaux d’huile, des systèmes de refroidissement, et s’assurer qu’aucune alarme n’est active sur le tableau de contrôle.
A-Démarrage : Mise en route des systèmes auxiliaires, comme les pompes de circulation d’huile et les systèmes de ventilation, puis démarrage du moteur ou du générateur en utilisant le bouton de démarrage ou une séquence programmée sur le panneau de commande.
- Suivi : Surveillance des indicateurs de pression d’huile, de température et de tension après le démarrage pour s'assurer que tout fonctionne correctement.
- Identification et correction immédiates de tout dysfonctionnement.
- Patientez 15 min avant de démarrer le second moteur en suivant la même procédure.
B-Extinction : Arrêt contrôlé des moteurs ou générateurs une fois les opérations terminées, avec arrêt progressif des systèmes auxiliaires et contrôles finaux pour s'assurer que le système est prêt pour une nouvelle utilisation.

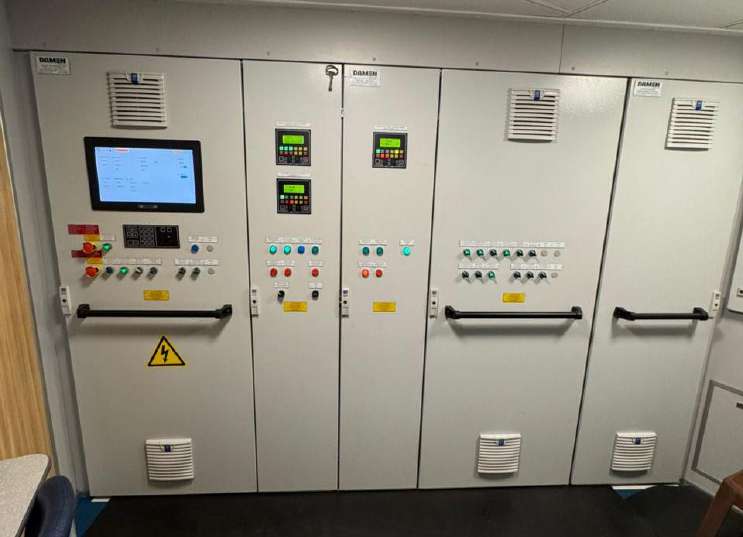
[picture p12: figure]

Figure 14 : Salle de commande de la salle machine des remorqueurs 11-Sondage et remise à niveau du gasoil : Sondage des niveaux de gasoil dans les différents réservoirs des navires et ajout de carburant si nécessaire pour maintenir des niveaux.
Pour cela, il faut :
- Faire le sondage et relevé chaque niveau de gasoil dans les différents réservoirs et comparer les valeurs obtenues ;
- Disposer toutes les vannes de manière correcte ;
- Aller à la salle de commande pour lancer la pompe de transfert ;

22

- Suivre le processus avec attention et délicatesse jusqu’à la fin.

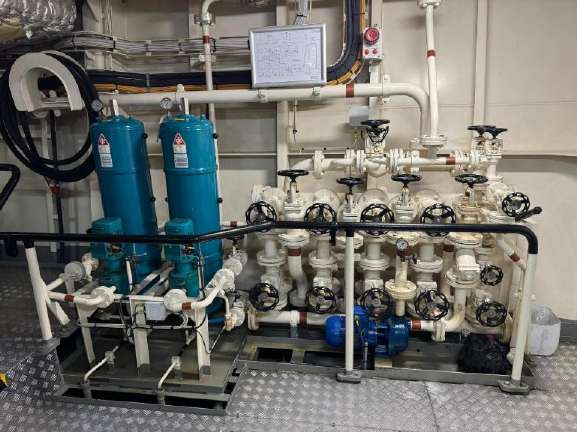
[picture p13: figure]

Figure 15 : Circuit de transfert de gasoil

12- Entretiens des circuits d'Aération et de la climatisation
Par ailleurs, les filtres à air des systèmes de ventilation mécanique et de climatisation ont fait l’objet d'un nettoyage soigné. Celle étape garanti un apport d'air frais suffisant pour le refroidissement optimal des moteurs ainsi qu'un environnement de travail sain a bord des remorqueurs.

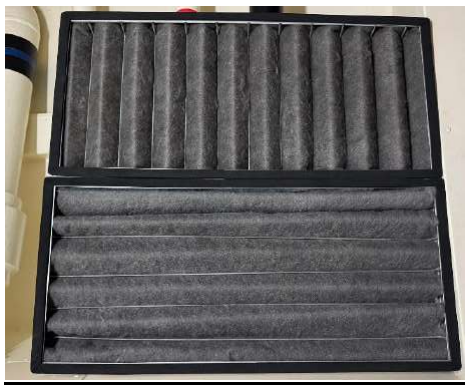
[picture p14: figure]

Figure 16 : Image des filtres du système de la climatisation de BIO-GUERRA. 13- Vidange des générateurs
La vidange des générateurs est une opération essentielle pour maintenir son bon fonctionnement et prolonger la durée de vie des GE. Elle consiste à vider l'huile usagée du générateur dans un bac et le remplir d'une huile neuve. La vidange s'effectue après 250 heures de fonctionnement d'un générateur. Il est recommandé d'utiliser l'huile recommandée par le fabricant et de remplacer un nouveau filtre à huile à chaque vidange.

23

Voici les étapes générales suivies pour faire la vidange :
1. Couper l'alimentation électrique du moteur
2. Laisser le moteur refroidir complètement
3. Dévisser le boulon de vidange et laisser couler l'huile usagée dans un bac
4. Dévisser le filtre à huile, nettoyer le logement du filtre puis installer un nouveau filtre à huile
5. Verser l'huile neuve par l'orifice de remplissage jusqu'au niveau indiqué
6. Vérifier à nouveau le niveau d'huile après quelques minutes de fonctionnement

Figure 17: Image montrant le GE tribord de AMAZONE

24

### 1.5 COMPETENCES ET DIFFICULTES RENCONTREES 1.5.1 COMPETENCES

Au cours de mon stage en tant que mécanicien au Port Autonome de Cotonou, j'ai acquis des compétences dans le domaine de la maintenance des équipements marins. Cela m'a également permis de participer à des exercices dits de sécurité et de me familiariser avec les nouvelles technologies de navigation notamment le système ASD des remorqueurs Amazone et Bio-Guerra. En travaillant sur les moteurs principaux, les générateurs électriques et les équipements de contrôle, j'ai effectué des interventions préventives et correctives renforçant ainsi mes acquis et mes connaissances en opérations de maintenance tout en me confrontant aux défis de la mer.

### 1.5.2 DIFFICULTES RENCONTREES LORS DU STAGE

J’ai rencontré de nombreuses difficultés au cours de mon stage au « PAC » notamment dans ma première semaine d’immersion dans le milieu marin :

- Mal de mer durant ma première semaine lorsqu’on est en manœuvre ou en mission en haute mer.
- Difficulté d’adaptation à la salle des machines des pilotines compte tenu de l’espace restreint et de la chaleur qui y règne surtout en manœuvre lors d’une ronde.
- Difficulté à collaborer avec l’équipage dans ma première semaine ;
- Difficulté à maitriser les différents systèmes principaux et auxiliaires des remorqueurs au début de mon stage (il y en a une panoplie et il a fallu du temps pour m’adapter)

Mais j’ai réussi avec brio à m’adapter efficacement au milieu marin, aux normes de sécurité et aux différents systèmes des pilotines et des remorqueurs.

25

26

### 1.6 GENERALITES SUR LA REALISATION D’UN CHALUMEAU UTILISANT

L’HYDROGENE COMME COMBUSTIBLE.

### 1.6.1 HISTORIQUE DU CHALUMEAU OXYHYDRIQUE

Le docteur Robert-Rare, professeur de philosophie naturelle à l’Université de Philadelphie, a annoncé, dans un mémoire (inséré dans le 1er volume du Journal minéralogique de Bruce) qu’il avait réussi à produire sur différents corps, des flux très-intenses de chaleur par un jet de flamme à partir d’un mélange d’hydrogène et d’oxygène dans la proportion requise pour former l’eau.

En 1816, M. Brooks annonça, dans les annales de Thomson, qu’il avait conçu un chalumeau dans lequel il condensait l'air au moyen d'une petite pompe de compression, pour le faire sortir en un jet très dense et continue. Il ajouta que ce jet, dirigé sur la flamme d’une lampe, produirait un flux de chaleur plus élevé que celui qu’on obtient avec le chalumeau ordinaire.

M. Newman construisit un chalumeau suivant l’idée de M. Brooks, en prenant en considération la facilité de son démontage. Il y ajouta une vis latérale par laquelle peut être introduit dans le récipient, l’oxygène ou tout autre gaz.

Sir H. Davy ayant reconnu que l’explosion d’un mélange de gaz oxygène et hydrogène ne se communiquerait pas dans l’intérieur des tubes à très-petites ouvertures. Il ajouta qu’il n’y aurait aucun danger d’explosion en brûlant les gaz comprimés à leur sortie d’un tube de verre de 3 pouces (76 millimètres) de long et de 1/80 pouce (0,52 millimètres) de diamètre.

Dr M. Clarke exploita les travaux de H. Davy pour les appliquer au chalumeau de Newman, en ajoutant aussi quelques modifications proposées par le professeur Cummings. Ces modifications consistaient à établir dans une boîte de fer un petit cylindre de sûreté, rempli a environ moitié d’huile, et garni à son extrémité supérieure d’une toile métallique très-fine. Les gaz condensés dans la boîte sont forcés de passer à travers l’huile dans un petit cylindre, pour ensuite traverser une toile métallique, avant d’arriver vers un robinet, à travers lequel ces gaz doivent s’écouler [7]

27

### 1.6.2 DESCRIPTION D’UN CHALUMEAU

Un chalumeau est un dispositif à travers lequel on obtient une flamme stable, de propriétés déterminées, par la combustion d’un mélange adéquat de gaz combustible et d’oxygène. [7] Il peut être utilisé pour diverses fonctions : soudage, brasage, chauffage et découpage. Il est composé de :

-Corps comprenant les arrivées de gaz à l’aide de robinets de réglages, généralement la manche du chalumeau ;

-Un mélangeur ;

-Une lance qui conduit le mélange ;

-Une buse calibrée (orifice de sortie).

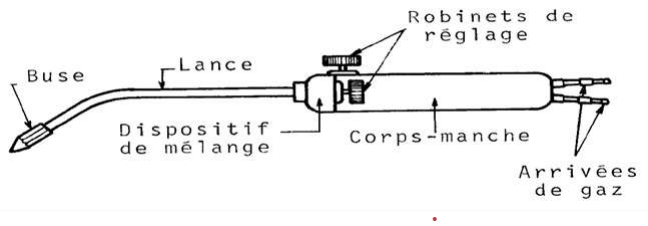
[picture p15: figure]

Figure 18 : Schéma descriptif d’un chalumeau. [7]

On distingue généralement deux types de dispositifs de chalumeaux. La figure montre les photos des dispositifs utilisés. [7]

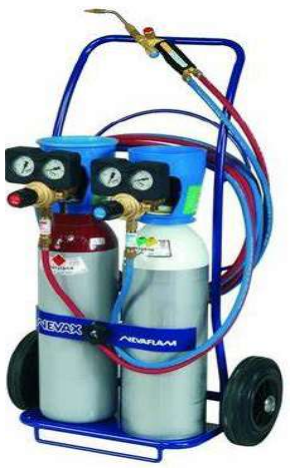
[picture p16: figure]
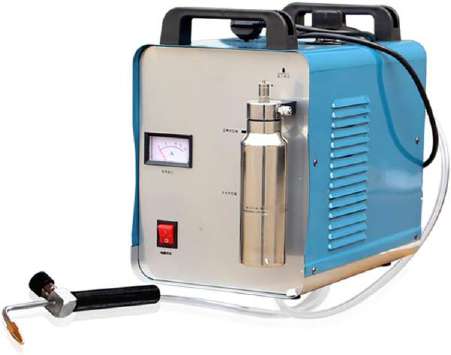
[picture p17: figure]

Figure 19 : Chalumeau classique | Figure 20 : Chalumeau oxyhydrogène

28

### 1.6.3 UTILISATION D’UN CHALUMEAU A HYDROGENE PAR RAPPORT AU CHALUMEAU OXYACETYLENIQUE

Actuellement, le brasage/soudage et d'autres procédés industriels à la flamme utilisent couramment des gaz en bouteille hautement inflammables comme le propane et l'acétylène.

Le stockage de ces gaz dans des bouteilles à haute pression augmente le risque d'accident et les coûts d'assurance pour le transport, les installations et les opérateurs. Ces procédés sont essentiels dans des secteurs tels que le pétrole et le gaz, le transport, la construction, la réparation automobile et la métallurgie, et sont souvent utilisés par les travailleurs des petites industries du monde entier. Ils sont largement utilisés dans diverses applications via les flammes de combustible et d'oxygène des chalumeaux manuels pour le brasage, la fabrication, le coupage et le soudage. [8]

L'acétylène est un gaz extrêmement instable, capable de se décomposer vigoureusement, même en l'absence de source d'oxygène. Ce gaz, certes important et utile, est hautement inflammable et sa forte énergie le rend très dangereux.

La quantité importante de chaleur dégagée par la décomposition du gaz acétylène provoque généralement une explosion d'une énergie plus importante. En raison de ces propriétés, l'acétylène est généralement stocké dans des bouteilles sous pression spéciales. Ces bouteilles de gaz comprimé sont connues pour subir des défaillances graves, se fendant généralement axialement et se brisant en de nombreux morceaux. Des preuves ont montré que ces fragments peuvent parcourir 200 m depuis les lieux de l'accident (Mirzaei, 2008). Il a été établi que le début de la décomposition dans tous les accidents est lié à la valve de la bouteille. Le gaz acétylène contenu dans les bouteilles sous pression peut également être mortel en cas d'incendie en raison de la formation d'éclats en cas d'explosion.

Selon le rapport du Bureau of Labor Statistics des États-Unis, chaque année, 20 décès et 6 000 blessures sont enregistrés à la suite d'accidents liés à des gaz compressifs tels que l'acétylène, l'argon, le propène, etc. Ces risques et accidents rendent impératif de trouver des mesures efficaces et des alternatives au gaz acétylène pour éviter une explosion. [8]

Dans cette étude, les auteurs ont développé un gaz plus respectueux de l'environnement en séparant l'eau en hydrogène et en oxygène gazeux (HHO) par électrolyse de l'eau. Cette technologie utilise un électrolyseur portable alimenté par une alimentation électrique monophasée. L'électrolyse alcaline de l'eau, une technologie bien établie, est un procédé disponible dans le commerce permettant de générer l'hydrogène et l'oxygène gazeux en deux flux distincts connectés à un chalumeau à flamme basse pression. L'hydrogène et l'oxygène gazeux produits peuvent être contrôlés individuellement et brûlés au niveau du brûleur mixte de surface en mélangeant l'hydrogène et l'oxygène gazeux (oxyhydrogène) en proportions. Cela signifie que la chimie de la flamme est contrôlée par la réduction de l'hydrogène et l'oxydation de l'oxygène dans des proportions adaptées à l'application.

29

La polyvalence de l'hydrogène en tant que vecteur énergétique et son efficacité en tant que carburant propre permettent son utilisation dans une large gamme d'applications dans plusieurs industries. [8]

Certaines utilisations principales de l'hydrogène dans différents secteurs sont répertoriées dans le tableau suivant :

Tableau : Quelques utilisations primaires de l’hydrogène dans différents secteurs industriels. [8]

Domaines d’applications | Méthodes de prévention | Avantage | Produits
Raffinage du pétrole | Hydrocraquage : casser les fractions de pétrole lourd en formes plus légères | Produit des combustibles de haute qualité à faible teneur en soufre | Saturer les hydrocarbures de craquage
Stockage de l’énergie | L’hydrogène absorbe l’énergie excédentaire pendant les périodes de faible demande et la libère lorsque la demande est élevée | Aide à équilibrer l’offre et la demande dans le réseau grâce à un mix énergétique variable | Production d’électricité pour une utilisation ultérieure
Mobilité-voiture | Electrolyse de l’eau | Environnement sain, énergie-vert et efficace | Hydrogène
Exploration spatiale | L’hydrogène sous forme d’hydrogène liquide (LH2) est utilisé comme propulseur | Cette réaction est très énergique et efficace, contribuant à une poussée puissante. | Propulsion par fusée

## 1.6.3.1 AVANTAGES ET INCONVENIENTS D’UN CHALUMEAU A HYDROGENE PAR RAPPORT A UN CHALUMEAU CLASSIQUE

Sur la base des données que nous avons collectées et mentionnées ci-dessus, le tableau suivant récapitule les avantages et inconvénients de chaque chalumeau.

30

Tableau 5: Récapitulatif des avantages et inconvénients des chalumeaux oxhydriques et classiques. [7]

Type de chalumeau | Avantages | Inconvénients
Oxhydrique | -Produit une flamme de très haute température, 3300 °C ; -utilise un combustible renouvelable ; [9] -La flamme d’hydrogène et propre et n’apporte d’impuretés lors du soudage ; -vitesse de coupage assez élevée 520mm/min ; -peut fonctionner à une haute pression, ce qui permet son utilisation sous l’eau, (6m de profondeur). - ne contient que le dispositif d’électrolyse et donc peu encombrant ; | -production de l’hydrogène et consomme de l’énergie ; -dispositif relativement chère et lourd ; -la flamme est peut-être invisible ; -problème de stockage et risque de fuite de l’hydrogène vu sa faible densité ; [7] -technologie nouvelle et peu disponible sur le marché.
Oxyacétylénique | -produit une flamme assez puissante, 3200 °C ; -disponible sur le marché ; -relativement pas chère. | -utilise un combustible fossile ; -produit du CO2 qui est néfaste pour l’environnement et l’opérateur ; -ne peut être utilisé qu’à des pressions relativement basses ; -consomme beaucoup de combustible 1000 l/h. - dispositif encombrant ; -risque de retour de flamme.

## 1.6.4 APPLICATION DU CHALUMEAU A HYDROGENE SUR LES NAVIRES POUR LES TRAVAUX EN MER (CAS DES REMORQUEURS DU PORT

AUTONOME DE COTONOU).
Dans le cadre des activités de maintenance navale, compte tenu des difficultés rencontrées au cours de mon stage dans les opérations comme le soudage, le brasage et le chauffage, nous avons pensé à l’introduction de notre dispositif sur les remorqueurs du Port Autonome de Cotonou.

31

a. Utilisation directe de l’eau de mer comme ressource
- Grâce à un système d’électrolyse embarqué, l’hydrogène sera directement produit à partir de l’eau de mer, abondante et gratuite.
- Cela rend le système autonome, sans dépendance au ravitaillement en gaz extérieur.
b. Sécurité renforcée
- L’hydrogène est produit à la demande, donc pas de stockage à haute pression à bord, contrairement aux bouteilles d’acétylène.
- En cas de fuite, l’hydrogène se dissipe rapidement dans l’air, réduisant les risques d’explosion.
c. Respect de l’environnement marin
- L’hydrogène ne produit que de la vapeur d’eau lors de la combustion.
- Cette technologie permet de réduire les émissions polluantes dans un port qui cherche à s’inscrire dans une dynamique écologique. [10]
d. Autonomie énergétique pour les travaux en mer
- Les travaux de soudage, brasage et chauffage peuvent être réalisés en pleine mer, sans dépendre d’un ravitaillement en gaz.
- Cela augmente la réactivité et la flexibilité du navire pour les interventions techniques.

e-Image d’un port moderne et vert [10]

- L’adoption du chalumeau à hydrogène positionne le Port Autonome de Cotonou comme acteur innovant dans la transition énergétique maritime en Afrique de l’Ouest.
f. Réduction des coûts opérationnels
- Moins de dépenses en achat, transport et stockage de gaz industriels.
- Possibilité d’équiper plusieurs navires avec des systèmes autonomes de production d’hydrogène.
g. Renforcement de la sécurité du personnel
- Moins de manipulation de gaz dangereux.
- Réduction des risques d’explosion et d’accidents.
h. Conformité aux normes internationales
- Le port se conforme aux normes environnementales de l’OMI (Organisation Maritime Internationale) et du règlement MARPOL sur la pollution.)

32

Tableau 6 : Chalumeau à hydrogène à bord d’un navire.

Le chalumeau à hydrogène est nettement plus adapté à un usage à bord de navires pour sa sécurité accrue, sa portabilité, son absence d'émissions polluantes et sa compatibilité avec les nouvelles normes écologiques du secteur maritime. [11]

Cela constitue une avancée technologique, sécuritaire et écologique pour les opérations de maintenance en mer. Dans le cas du remorqueur du Port Autonome de Cotonou, cette innovation répond aux enjeux actuels de performance, durabilité et autonomie énergétique. C’est un pas décisif vers un port intelligent, propre et tourné vers l’avenir

Critère | Chalumeau à hydrogène | Chalumeau oxyacétylénique
Sécurité à bord | Produit le gaz à la demande, donc pas de stockage de gaz inflammable – réduit les risques d’explosion | L’acétylène est instable et hautement explosif, nécessitant un stockage sous pression dangereux
Compacité & mobilité | Appareils légers et compacts, faciles à transporter dans les zones confinées du navire | Encombrants, nécessite des bouteilles d’oxygène et d’acétylène lourdes
Émissions en environnement clos | Produit uniquement de la vapeur d’eau : pas de CO ni de fumée toxique | Génère CO2 , CO, suies, polluants dans des espaces clos
Maintenance et logistique | Nécessite peu de logistique : pas de bouteilles à remplacer, juste de l’eau et de l’électricité | Nécessite un approvisionnement constant en gaz, gestion des bouteilles
Écologie maritime | Idéal pour les navires à empreinte carbone réduite (zéro CO ) | Forte empreinte carbone, inadapté aux normes environnementales strictes

33

### 1.7 METHODOLOGIE

Description et fonctionnement du chalumeau à hydrogène:

Production d’hydrogène par électrolyse de l’eau :

Il existe plusieurs méthodes pour produire de l’hydrogène. On ne s’est limité qu’à seulement une méthode, la plus courante : l’électrolyse de l’eau. L’électrolyse de l’eau est une réaction électrochimique qui vise à séparer la molécule d’eau liquide en deux gaz, le dihydrogène et le dioxygène, sous la forme. [7]

2H20 → 2H2 + O2
(1.1)

Cette réaction est produite lorsqu’un courant continu se déplace de l’anode à la cathode en passant par l’eau, il dissocie la molécule d’eau en ion (OH-) et (H+). Les ions d’hydrogène acceptent un électron à la cathode selon la réaction de réduction

2H

+ + 2e

− → H2
(1.2)

Pendant que dans l’anode, les ions d’hydroxyde perdent des électrons selon la réaction d’oxydation

2H2O → O2 + 4H

+ + 4e

− (1.3) s

La combinaison de l’équation (1.1) et (1.2) donne l’équation (1.3)

Cette réaction nécessite entre 1,8 et 2,4 volts pour démarrer. [7]

Pour obtenir de meilleurs résultats, un ajout d’électrolyte dans l’eau est nécessaire, car l’eau pure n’est pratiquement pas conductrice ce qui rend la réaction très lente. L’électrolyte est une substance hydrosoluble qui se dissout et se dissocie en anions et cations. Les ions permettent au courant de se déplacer plus rapidement entre les électrodes. Généralement on utilise des acides, des bases ou des sels. Ainsi, le choix de l’électrolyte doit prendre en considération les ions libérés car ils vont entrer en compétition avec les ions d’hydrogène et avec l’hydroxyde pour le gain ou la perte d’électrons. Il faut que le potentiel standard d’électrode des anions soit inférieur à celui de l’hydroxyde pour permettre la production du dioxygène et que le potentiel standard d’électrode des cations soit supérieur à celui des ions d’hydrogène pour qu’il y est production du dihydrogène. De plus, tous les matériaux conducteurs peuvent être pris comme électrode, mais ils ne sont pas tous efficaces. A titre d’exemple, le cuivre et le fer sont de mauvais matériaux, car ils s’oxydent facilement et l’électrolyse augmente l’effet d’oxydation. Il est donc beaucoup plus avantageux d’utiliser des matériaux comme l’acier inoxydable, le platine ou le titane qui se rouillent très peu voire pas du tout. [7]

Types de générateurs

Pour produire le dihydrogène et le dioxygène, nous allons utiliser un générateur du type HHO. Ce générateur est une succession de plaques métalliques reliées à un générateur de courant continue de sorte à alterner entre plaque reliée au pôle positif et plaque reliée

34

au pôle négatif successivement. La figure suivante montre le schéma de la disposition des plaques du générateur. [7]

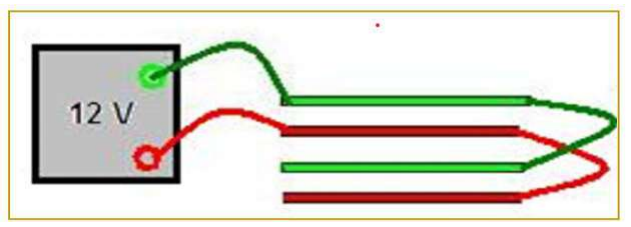
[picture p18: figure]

Figure 21 : Schéma de la disposition des plaques. [7]

Entre ces plaques, on met des plaques non connectées au générateur électrique qu’on appelle plaque neutres. Ces plaques vont jouer le rôle de pont pour les ions, ce qui aura pour effet de réduire la tension entre les plaques.

Figure 22: Schéma de la disposition des plaques avec plaques neutres [7]

Dans l’exemple représenté sur la figure 1, la tension entre une plaque rouge et une plaque verte est de 12V. Si on pose une plaque neutre, comme sur la figure 2, qui est un métal conducteur, elle sera soumise aux champs électriques crées par les deux autres plaques. Ces champs vont appliquer une force qui va attirer les charges positives d’un côté et les charges négatives de l’autre. Le déplacement de ces charges vers les deux extrémités va créer un déséquilibre électrique et donc l’apparition d’un champ électrique induit, à l’intérieur de la plaque neutre, qui s’opposera au champ régnant. Le mouvement des charges cessera et la plaque sera chargée positivement du côté en face la plaque reliée au pôle négatif, et vice versa.

Si la plaque grise est équidistante par rapport aux plaques, rouge et verte, la tension entre la plaque neutre (grise) et la plaque rouge ou verte sera divisée en deux, donc de 6V. L’intérêt de rajouter ces plaques neutres réside dans l’augmentation de la surface de production des gaz tout en diminuant la tension entre les plaques du générateur afin d’éviter la surchauffe de l’eau et la présence de la vapeur d’eau dans notre mélange. De plus, il est difficile de trouver un générateur électrique qui peut produire un courant d’intensité élevée (cinquantaine d’Ampère) et une faible tension (entre 4 et 6 volts). Toutes les plaques sont séparées par un isolant afin d’empêcher tout contact entre elles. L’ensemble de plaques positives et négatives s’appelle : cellule [9]

35

Il existe deux types de cellules : les cellules submergées où les plaques sont à l’intérieur de l’eau (Wetcell) et les cellules non submergées où l’eau circule entre les plaques et où le système est étanche (Dry cell). Les figures montrent respectivement des photos de cellules, humide et sèche (Wet and Dry cells).

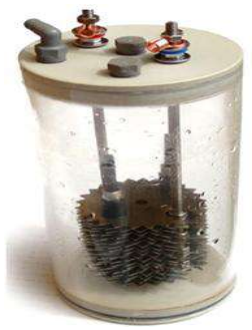
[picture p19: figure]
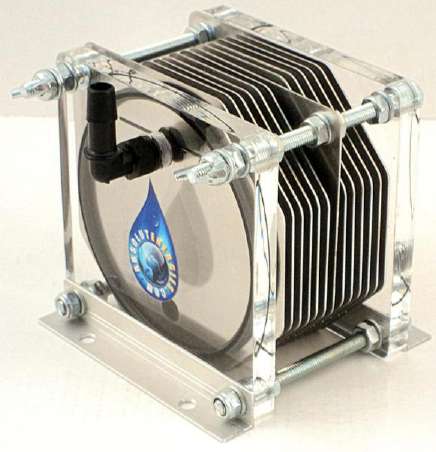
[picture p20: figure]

Figure 23 : Drycell | Figure 24 : Wetcell

Dans le cadre de ce projet de fin d’études, nous avons réalisé le prototype d’un chalumeau à hydrogène utilisant un générateur Drycell.

### 1.7.1 LES PRINCIPAUX ELEMENTS DU CHALUMEAU OXYHYDRIQUE

Le dispositif expérimental du chalumeau à hydrogène avec cellule non immergée (drycell) est composé de 12 éléments : un panneau photovoltaïque, une batterie de 24V/10Ah, un régulateur de charge, une alimentation électrique, une cellule produisant du dihydrogène et du dioxygène (dry cell), un réservoir d’eau, une pompe de circulation de l’eau, un cartouche filtrant en résine, séparateur eau-gaz, support, accessoires de canalisation complet et un bec de chalumeau.

### 1.7.1.1 ROLE ET PLAN DE CHAQUE ELEMENT

- Générateur HHO (Drycell)

Le générateur Dry Cell utilise des plaques en acier inoxydable 316 pour produire du gaz HHO. L'hydrogène ainsi produit devient le combustible principal du chalumeau. Il

36

permet de maintenir une production continue de gaz, assurant un fonctionnement stable et constant du chalumeau pendant son utilisation.

- Bec chalumeau

Le bec est conçu pour diriger et contrôler la flamme produite par la combustion de l’hydrogène, garantissant une application précise pour des tâches comme la soudure ou la découpe. Pour cela, il inclure une chambre de mélange où l’hydrogène se combine avec l’oxygène (souvent issu de l’électrolyse) dans des proportions contrôlées pour optimiser la combustion.

- Panneau solaire Longi 355-375W

Il capte l’énergie solaire et la convertit en électricité pour alimenter le système, notamment la recharge des batteries et l’alimentation du générateur HHO.

- Régulateur de charge solaire 40A 12/24V

37

Il régule la tension et le courant provenant du panneau solaire pour éviter la surcharge ou la décharge excessive des batteries, assurant ainsi la sécurité et la longévité du système.

- Batterie LiFe O₄ 24V 10Ah

Elle stabilise et stocke l’énergie électrique produite par le panneau solaire, servant de source d’alimentation fiable et continue pour le fonctionnement du drycell et du chalumeau.

- Cartouche filtrant en résine

Élimine les impuretés présentes dans l'eau afin de protéger l'électrolyseur et maintenir un rendement optimal.

- Séparateur eau-gaz

Sépare l'hydrogène produit de l'eau restante pour garantir une extraction efficace du gaz.

- Une alimentation électrique

38

Active le processus d'électrolyse pour séparer l’hydrogène et l’oxygène.

- Pompe à circulation d’eau

Fait circuler l'eau dans le système pour garantir un fonctionnement efficace.

- Réservoir d'eau

Stocke l'eau pure utilisée dans la réaction.

- Ensemble de tuyaux

Permet de relier tous les composants et d'assurer le bon acheminement des fluides.

39

### 1.7.2 DIMENSIONNEMENT DU CHALUMEAU OXYHYDROGENE

- DIMENSIONNEMENT DU GENERATEUR HHO (DRYCELL)

### Hypothèses

-Le chalumeau sera capable de fournir une flamme capable de souder, de braser et de découper une tôle d’épaisseur de 0,8mm maxi.

Débit d’hydrogène nécessaire

Partons du principe de l’oxyacétylène

### 1. Cas du chalumeau oxyacétylène – tôle de 0,8 mm

Débit d’acétylène typique

Pour une tôle de 0,8 mm, on estime un débit entre 150 et 300 ml/min

- On retient une valeur cible de 250 ml/min

Vitesse d’avance typique

Pour cette épaisseur, la vitesse de coupe est un peu réduite :

- Estimation : 250 à 500 mm/min
- On prend une vitesse moyenne de 400 mm/min

### 2. Conversion pour le chalumeau oxyhydrogène

Pouvoir calorifique :

Acétylène ≈ 50 MJ/kg

Hydrogène ≈ 119 MJ/kg

Mais par litre à 1 ATM :

Acétylène ≈ 25 kJ/L

Hydrogène ≈ 11.9 kJ/L

On retient donc que le débit d’hydrogène doit être ≈ 2,5 fois supérieur pour compenser la différence énergétique.

Débit équivalent :

- 250 ml/min × 2,5 = 625 ml/min
- Plage estimée de besoin : 600 à 750 ml/min d’hydrogène pour 0,8 mm

### 3. Calcul de la vitesse d’avance pour l’hydrogène

40

a- Énergie disponible (hydrogène)

Débit H₂ = 0,625 L/min

Pouvoir calorifique = 11 900 J/L

Efficacité thermique estimée = 70 %

Énergie disponible = Débit de gaz (L/min) ×Pouvoir calorifique (J/L) ×Efficacité

AN : Énergie disponible = 0,625 × 11 900 × 0,7 = 5 206 J/min

b- Énergie nécessaire par mm de coupe

🔹 Masse du métal à chauffer (par mm d’avance)

Masse (g)=Volume (cm3) ×Densité (g/cm3) Déterminons le volume

Volume = Épaisseur de la tôle × Largeur de la coupe × Longueur (1 mm de coupe).

Épaisseur = 0,08 cm

Largeur ≈ 0,1 cm

Longueur = 0,1 cm

Volume = 0,08 × 0,1 × 0,1 = 0,0008 cm³

Densité = 8 g/cm³ (acier inox)

Masse = 0,0008 × 8 = 0,0064 g

🔹Énergie = m × c × ∆T

Chaleur spécifique acier ≈ 0,5 J/g°C

∆T = 1175 °C

Énergie = 0,0064 × 0,5 × 1175 ≈ 3,76 J/mm

c-Vitesse d’avance

Vitesse = Énergie dispo / Énergie par mm

V = 5 206 / 3,76 ≈ 1 384 mm/min

Conclusion : le débit de 625 ml/min permet une vitesse de découpe largement suffisante (>1300 mm/min), bien au-dessus de la vitesse requise (~400 mm/min).

41

## 1.7.3 DIMENSIONNEMENT DU COURANT CONSOMMÉ

### 1. Hypothèse de base : loi de Faraday

La production d’hydrogène par électrolyse suit la loi de Faraday. Pour simplifier, on utilise la relation pratique suivante :

1 A ≈ 10,44 ml/min de H₂

### 2. Débit d’hydrogène en fonction du courant

- Débit cible : Q = 625 ml/min
- Courant nécessaire :

I =

Q
10. 44 = 60A

### 3. Puissance électrique absorbée

- Tension de cellule typique : 2,0 à 2,2 V
- Puissance absorbée :

P = U × I

P = 120W

- DIMENSIONNEMENT DE LA BATTERIE (24V / 10Ah)
- Tension nominale (U) : 24 V
- Capacité (C) : 10 Ah
- Énergie stockée :

E = U × C

E = 240Wh

- Consommation du drycell : 120 W
- Autonomie théorique :

Autonomie =

E
P

Autonomie = 2heures

La batterie LiFe O₄ 24V/10Ah peut donc alimenter le système pendant environ 2 heures sans recharge.

42

- DIMENSIONNEMENT DU PANNEAU PHOTOVOLTAÏQUE (355–375W)

### 1. Production théorique :

- Puissance crête : 355–375 W à 24 V
- Courant maximum (approximatif) :

I =

Puissance crête
Tension

I ≈ 15, 6A

### 2. Énergie quotidienne produite (ensoleillement moyen de 5 h/jour) :

- Production max (Pmax) par jour :

Pmax =

Puissance crête
Durée d′ensoleillement

Pmax = 1875Wℎ/jour

### 3. Capacité à alimenter le système :

- Consommation journalière (Cj) si fonctionnement 2 h :

Cj = P × 2heurs

Cj = 240Wh

Le panneau produit largement plus d'énergie que nécessaire (≈ 1 875 Wh), permettant :

- La recharge complète de la batterie (240 Wh)
- L’alimentation directe du générateur HHO pendant l’ensoleillement

Tableau 8: Récapitulatif du dimensionnement

Elément | Valeur estimée
Débit H2 cible | 625ml/min
Nombre de plaques | 8 plaques ( surface active : 800cm²)
Courant total requis | 60A
Densité du courant | 0,075A/cm²
Tension cellule (typique) | 2,0V
Puissance absorbée | 120W
Consommation système (24 V) | 5 A
Batterie | 24 V / 10 Ah → 2 h d’autonomie
Panneau photovoltaïque | 355-375W→ jusqu'à 1 875 Wh/jour

43

### 1.7.4 ETAPES DE LA REALISATION DU CHALUMEAU A HYDROGENE

### 1. Acquisition des composants

Procéder à l'achat de l'ensemble des matériels nécessaires au montage du système, notamment :

- Générateur HHO (Drycell)
- Réservoir d’eau
- Cartouche filtrante à résine
- Séparateur eau-gaz
- Pompe de circulation
- Alimentation électrique (batterie 12V, régulateur, panneau photovoltaïque)
- Tuyauterie et raccords pneumatiques
- Bec de chalumeau
- Câblage et accessoires de fixation

### 2. Assemblage mécanique des sous-ensembles

Fixation rigoureuse de chaque composant sur un support stable, selon un agencement logique permettant un bon écoulement des fluides et un câblage sécurisé.

Fixation du séparateur eau-gaz
Fixation de la cartouche filtrante à résine
Installation du réservoir d’eau
Montage et fixation du générateur HHO (Drycell)
Installation de la pompe de circulation d’eau
Intégration du bloc alimentation électrique (batterie, régulateur, bornier)

### 3. Raccordement hydraulique et gaz

- Interconnexion de tous les composants via des tuyaux transparents haute résistance.
- Utilisation de raccords pneumatiques pour garantir l’étanchéité et faciliter la maintenance.
- Vérification du sens de circulation de l’eau et du flux de gaz HHO (de la cellule jusqu’au bec du chalumeau, via le séparateur et le filtre).

### 4. Câblage électrique

- Connexion du Drycell à l’alimentation électrique (batterie 12V)
- Connexion de la pompe de circulation à la même source
- Intégration du panneau photovoltaïque pour assurer la recharge de la batterie
- Mise en place de protections : relais, selon le schéma électrique

### 5. Mise en service et tests fonctionnels

- Remplissage du système avec une solution électrolytique
- Démarrage progressif de l’électrolyse pour observer la production de gaz HHO

44

- Vérification de la circulation d’eau via la pompe
- Contrôle de la présence de fuites (gaz ou liquide)
- Allumage du chalumeau à hydrogène et ajustement de la flamme
- Réalisation de tests de coupe et de brasage sur une tôle métallique (épaisseur 0,8 mm)

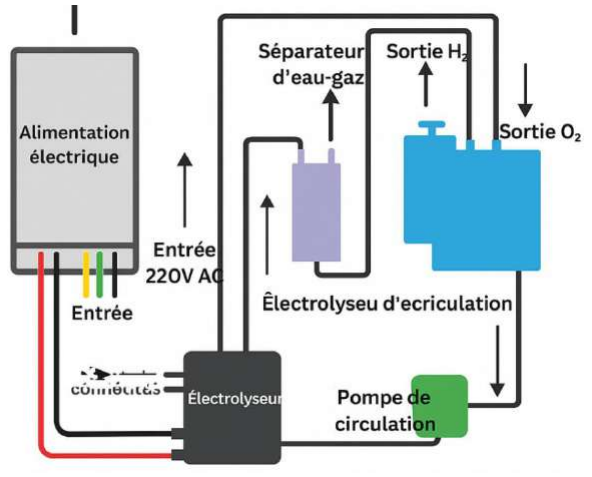
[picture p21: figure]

Figure 25 : Schéma de câblage

## 1.7.5 VUE EN PERSPECTIVE DU CHALUMEAU A HYDROGENE

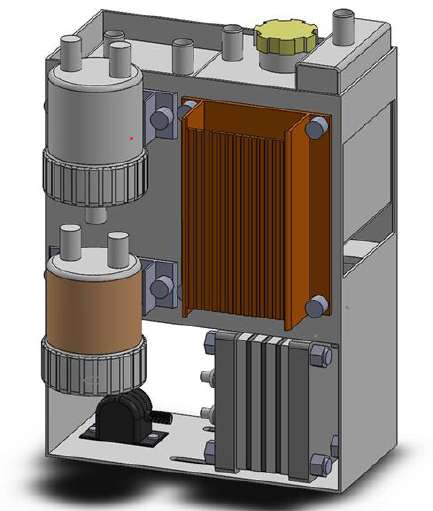
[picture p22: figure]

Figure 26 : Conception assistée par ordinateur du chalumeau à hydrogène (SolidWorks)

45

## 1.8 RESULTATS ET DISCUSSIONS

Présentation des solutions électrolytiques envisagées

Dans le cadre de la réalisation d’un chalumeau utilisant l’hydrogène comme combustible, plusieurs solutions électrolytiques ont été identifiées pour la production d’hydrogène par électrolyse :

- Eau + Bicarbonate de sodium (NaHCO₃)
- Eau de mer
- Eau + Hydroxyde de potassium (KOH)

Pour la mesure du débit, nous avons utilisé la méthode de mesure par déplacement d’eau qui stipule que le volume de gaz produite est proportionnel au déplacement d’eau.

Figure 27 : Mesure par déplacement d’eau

## 1.8.1 RESULTATS EXPERIMENTAUX

a) Solution NaHCO₃ (bicarbonate de sodium)

Le premier test a été effectué avec une solution d’eau et de bicarbonate de sodium. L’électrolyse a été lancée avec succès. Le gaz produit a été mesuré par déplacement d’eau :

- Volume produit : 500 ml en 30 secondes
- Débit estimé : 1 L/min
b) Eau de mer

Testée en plein air avec la production d’un volume de 350 ml en 30 secondes.

- Débit estimé : 0,7 L/min.
c) Solution KOH

Solution estimée comme la plus performante avec un débit estimé de 1,4 à 1,6 L/min. Testée par la suite et confirmée comme la plus efficace. Elle offre une excellente conductivité ionique et une production stable et rapide d’hydrogène.

46

Influence de la concentration massique sur le débit obtenu (NaHCO₃, KOH)

Lors des tests nous avons constaté une influence de la concentration massique des électrolytes sur le débit d’hydrogène produit. Le tableau et le graphique suivants nous révèle ces données.

Tableau 10 : Influence de la concentration massique sur le débit obtenu (NaHCO₃, KOH)

Concentration (%) | Débit H₂ (L/min) - Bicarbonate | Débit H₂ (L/min) - KOH
1 | 0.2 | 0.3
2 | 0.4 | 0.6
3 | 0.6 | 0.9
4 | 0.8 | 1.2
5 | 0.9 | 1.3
6 | 1.0 | 1.4-1.6
7 | 0.95 | 1.35
8 | 0.9 | 1.3
9 | 0.85 | 1.25
10 | 0.8 | 1.2

Figure 28 : Influence de la concentration massique sur le débit obtenu

L’interprétation de cette courbe montre que la concentration massique idéale pour notre drycell est d’environ 6% ce qui correspond à un débit de 1.6L/min pour le KOH et 1.0L/min pour le bicarbonate. Hormis cette valeur, le rendement du drycell est faible.

Comparaison des performances des trois solutions testées

47

Tableau 10 : Comparaison des performances

Solutions | Débit (L/min) | Sécurité | Disponibilité | Observations
Eau + NaHCO₃ | 1,0 | Très bonne | Très bonne | Facile à manipuler
Eau de mer | 0,6 | Moyenne | Excellente | Gratuit mais risque de dichlore
Eau + KOH | 1,4-1,6 (confirmé) | Moyenne | Moyenne | Très bon rendement, solution retenue

Série 1 : KOH

Série 2 : NaHCO₃

Série 3 : Eau de
mer

Figure 29 : Graphique des solutions électrolytiques testés.

La lecture du graphe montre que la solution du KOH est celle qui a donné un rendement meilleur par rapport aux autres et par conséquent elle sera celle qui sera retenue.

Solution retenue : KOH

Compte tenu des résultats obtenus lors des essais, la solution à base de KOH a été retenue comme étant la plus performante. Elle permet une production rapide et stable d’hydrogène, essentielle pour une utilisation continue dans un chalumeau. Malgré son caractère corrosif, une manipulation prudente permet d’en exploiter pleinement les avantages techniques.

## 1.8.2 TESTS AVEC LE CHALUMEAU

Des essais pratiques ont été réalisés avec le bec chalumeau alimenté par l’hydrogène produit via électrolyse de la solution KOH. Les observations sont les suivantes :

- Allumage : rapide et stable.
- Flemme : nette, concentrée, avec une longueur allant jusqu’à 10 cm.
- Température estimée : supérieure à 2000 °C, permettant la fusion rapide de métaux.
- Chauffage: acier et aluminium de fine épaisseur chauffés avec succès.
- Coupage : test de découpe réussi sur une plaque d’acier de 0,8 mm.

Ces résultats confirment que le système est fonctionnel et performant pour des travaux de soudage et de coupage à petite échelle.

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
Histogramme des solutions testés

Série 1 | Série 2 | Série 3

48

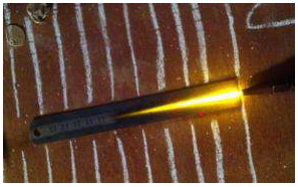
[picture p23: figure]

Figure 30: Photos de la flamme produite par le chalumeau conçu.

Avec la vanne du chalumeau on a fait varier la pression afin de voir le panache de la flamme. Cependant il nous était impossible de mesurer l’étendue du panache à l’œil nu par manque d’instrumentation adéquate à cet effet. Ceci est aussi valable pour la température de la flamme.

## 1.8.3 ETUDE ECONOMIQUE

- Coût de fabrication

Tableau 11: Coût du projet

Eléments | Prix total
Générateur HHO (Drycell) | 245,000 XOF
Les accessoires pour mise en circulation d'eau et d'hydrogène gazeux | 135,000 XOF
Câblerie et connecteur | 10,000 XOF
Panneau solaire Longi 355-375W | 50,000 XOF
Régulateur de charge solaire 40A 12/24V | 25,000 XOF
Batterie LiFe O₄ 24V 10Ah | 35,000 XOF
Bec chalumeau | 17,000 XOF
Transport | 120000 XOF
TOTAL | 637,000 XOF

Le prix de fabrication de notre prototype de chalumeau oxyhydrique est de 637,000 XOF

- Coût énergétique

Pour un fonctionnement normal d’une heure, le chalumeau à hydrogène consomme une solution aqueuse composée de 3 litres d’eau et de 1 % en masse de potasse (KOH), soit 30 g (0,03 kg). L’alimentation électrique est assurée par un panneau solaire de 375 W connecté à une batterie LiFe O₄ de 24 V – 10 Ah. Le générateur HHO présente une consommation moyenne de 120 W.

La consommation électrique horaire est donc :

E =

120 × 1
1000 = 0.12KWℎ

49

Cependant, dans le cadre de notre système, cette énergie est fournie par une source photovoltaïque, ce qui rend le coût énergétique lié à l’électricité nul.

- Le prix du KOH (potasse) est d’environ 1800 XOF/kg

Les éléments intervenant dans le calcul du coût énergétique sont détaillés dans le tableau suivant :

Tableau 12 : Résumé du coût énergétique.

| Eau | Électricité (solaire) | Potasse (KOH)
Consommation par heure | 3 L/h | 0,12 kWh/h | 0,03 kg/h
Prix de vente (XOF/h) | Gratuit | Alimenté par un PV | 1800 XOF/kg
Cout par heure | 0 XOF/h | 0 XOF/h | 54 XOF/h
Coût total (XOF/h) | 54 XOF/h

Ainsi, le coût énergétique de notre chalumeau s’élève à 54 XOF par heure de fonctionnement.

## 1.9 SUGGESTIONS OU RECOMMANDATIONS

Dans la perspective d’une application embarquée, notamment sur les navires, les futurs travaux devront se concentrer sur plusieurs axes d’amélioration :

Suggestions
- Optimisation de la production d’hydrogène

Il sera essentiel d’augmenter le rendement du système d’électrolyse en optimisant les paramètres opératoires (tension, température, concentration, débit), ainsi que la conception des électrodes et du réacteur.
- Automatisation partielle du système

Une automatisation intelligente (par microcontrôleur ou automate programmable) permettra de réguler les paramètres de fonctionnement en temps réel, d’assurer la sécurité (détection de gaz, surchauffe, surtension), et d’améliorer la stabilité de la production d’hydrogène.
- Amélioration de la solution électrolytique à base d’eau de mer

Puisque le système sera installé sur des navires, l’eau de mer — qui est naturellement disponible — sera utilisée comme solution électrolytique. Toutefois, des améliorations seront nécessaires

Recommandations
Mettre en place un protocole d’expérimentation systématique

Afin de tester différentes combinaisons de tension, concentration en électrolyte, température et débit de circulation pour identifier les conditions opératoires optimales.

50

Intégrer un microcontrôleur (type Arduino ou ESP32)

Avec des capteurs de température, tension, courant et détecteurs de gaz (H₂, Cl₂) pour surveiller les paramètres en temps réel.
Effectuer un prétraitement de l’eau de mer par filtration fine

Pour enlever les particules solides et éventuellement neutralisation partielle du chlore pour limiter les émissions toxiques.

Ces recommandations visent à rendre le système plus performant, plus sûr et plus adapté à un usage maritime continu, tout en exploitant de manière durable une ressource abondante comme l’eau de mer.

## 1.10 DIFFICULTES RENCONTREES

Nous avons principalement rencontré des difficultés avec certains instruments de mesure, tels que le manomètre et le débitmètre, dont le fonctionnement précis ou l’absence de matériel adapté a nécessité l’adoption d’autres techniques de mesure plus accessibles, bien que parfois moins précises.

Par ailleurs, la recherche et l’acquisition de l’électrolyte KOH (hydroxyde de potassium), essentiel pour l’électrolyse de l’eau, se sont avérées particulièrement compliquées en raison de sa disponibilité limitée sur le marché local et de la réglementation associée à sa manipulation. Cette contrainte a exigé une adaptation de notre approche expérimentale.

Nous avons également été confrontés à certaines limites en termes de connaissances en chimie, notamment sur les réactions d’électrolyse et la gestion des risques liés à la manipulation de gaz inflammables comme l’hydrogène et l’oxygène. Cela nous a amenés à approfondir nos recherches documentaires et à solliciter l’appui d’experts ou d’enseignants pour combler ces lacunes.

Enfin, la rédaction de l’état de l’art a posé quelques difficultés, notamment en ce qui concerne la sélection et l’analyse critique des sources. Toutefois, grâce à un travail de collaboration et à des efforts de révision, nous avons réussi à surmonter ces obstacles.

51

## CONCLUSION GENERALE

Ce stage de fin de formation m’a offert une précieuse opportunité de consolider mes acquis théoriques et de les confronter aux exigences du terrain, en particulier dans un environnement technique et maritime tel que celui du Port Autonome de Cotonou.

Par ailleurs, la réalisation d’un chalumeau utilisant l’hydrogène comme combustible représente une avancée technologique notable dans le domaine de la maintenance industrielle et maritime. Ce dispositif constitue une alternative écologique, sécurisée et innovante aux chalumeaux classiques à acétylène. Il permet non seulement de réduire considérablement les risques liés à la manipulation de gaz instables, mais aussi de limiter l’impact environnemental des opérations de soudage et de découpage grâce à une combustion propre, ne produisant que de la vapeur d’eau. L'intégration de ce chalumeau à hydrogène à bord des remorqueurs et vedettes constitue également une réponse pertinente aux défis actuels de sécurité, d’autonomie énergétique et de développement durable. Ce projet contribue ainsi à la modernisation des équipements navals, à l’amélioration des conditions de travail des techniciens, et à la transition énergétique dans le secteur portuaire.

52

## REFERENCES BIBLIOGRAPHIQUES

[1] Blogger, «Dans l'ère du temps,» 2010. [En ligne]. Available: http://danslredutemps.blogspot.com/2012/02/solaire-lalternative-energetique.html. . [Accès le 20 Avril 2025].
[2] «Energies nouvelles,» [En ligne]. Available: https://www.ifpenergiesnouvelles.fr/enjeux-et-prospective/decryptages/energies-renouvelables/tout-savoir-lhydrogene. [Accès le 15 Avril 2025].
[3] «UNSTIM-Abomey,» [En ligne]. Available: https://www.google.com/search?q=photos+de+unstim+centre+universitaire+d%27abomey.
[4] R. TOHODJEDE, «Réalisation d’un système d’essuie-glace pour le nettoyage optimal des panneaux,» UNSTIM-ENSGEP, Abomey, 2024.
[5] N. GUIDIDJAGO, «INVASION BIOLOGIQUE DE RONGEURS : PERCEPTIPONS DES,» Université d'Abomey-Calavi, UAC, Abomey-Calavi, 2018.
[6] C. A.-o. T. Aurel, «Rapport de stage effectué au Port Autonome de Cotonou,» Port Autonome de Cotonou, Cotonou, 2024.
[7] W. MAMERI et Y. TIAIBA, «Etude comparative et Réalisation d'un chalumeau utilisant l'hydrogène comme combustible,» Ecole Nationale Polytechnique d'Algérie, Département de Mécanique, ALGERIE, 2017.
[8] J. Attah, «L’oxy-hydrogène gazeux comme carburant durable pour l’industrie du soudage : alternative à l’oxy-acétylène gazeux,» vol. 9, n° %1 100160, 2024.
[9] M. I. d. d. s. à. l. r. Mohamed, Réalisation d’un chalumeau à hydrogène, Alger: Division Hydrogène-Énergies Renouvelables - CDER, 2017.

[10
]
A. d. France, «L’hydrogène : ressource énergétique pour le maritime ?,» L’hydrogène : ressource énergétique pour le maritime ?, 2020.

[11
]

Pyonnier, «Principaux usages de l'hydrogène,» p. 36, 2022.

[12
]

ADEME, Fiche Technique L'hydrogène dans la transition énergétique, 20, Avenue du Grésillé, Mars 2018.

53

## ANNEXES

ANNEXE 1 : Informations sur le panneau solaire et l’alimentation électrique du système

Tableau 13 : Détails sur le système d’alimentation du chalumeau à hydrogène

ANNEXE 2 : Composants du système HHO

Tableau 14 : Principaux éléments du générateur HHO

Composant | Description | Rôle
Générateur HHO | Cellule Drycell à plaques inox avec alliage en titane | Produit un mélange gazeux d’hydrogène et d’oxygène par électrolyse
Réservoir d’eau | Contenant d’eau déminéralisée | Alimente le générateur HHO
Pompe de circulation | Pompe électrique basse tension | Assure le déplacement constant de l’eau dans le système
Cartouche filtrante | Résine purificatrice | Protège le système contre les impuretés et les dépôts minéraux
Séparateur eau-gaz | Chambre de décantation | Empêche l’eau de remonter vers le bec du chalumeau
Bec de chalumeau | Sortie des gaz HHO | Permet la combustion pour le soudage, le brasage ou le découpage

ANNEXE 3 : Quelques photos du système de production et d’utilisation du gaz HHO

(a) : Vue en perspective du chalumeau à hydrogène avec les composants principaux
(b) : Vue 3D du générateur HHO (Drycell)
(c) : Schéma du dispositif complet en essai
(d) : Schéma d’assemblage électrique du panneau solaire, régulateur et batterie
(e) : Image du bec chalumeau avec les différentes buses
Équipement | Fonction principale | Détails techniques
Panneau solaire Longi 355–375 W | Production d’énergie renouvelable | Permet de recharger les batteries et d’alimenter le système de production HHO
Régulateur de charge 40A (12/24V) | Protection du circuit de charge | Évite les surtensions et la surcharge des batteries
Batterie LiFeO₄ 24V 10Ah | Stockage de l’énergie solaire | Fournit une alimentation stable pour la drycell et le reste du circuit
Alimentation électrique | Activation du processus d’électrolyse | Fournit le courant nécessaire pour séparer H₂ et O₂

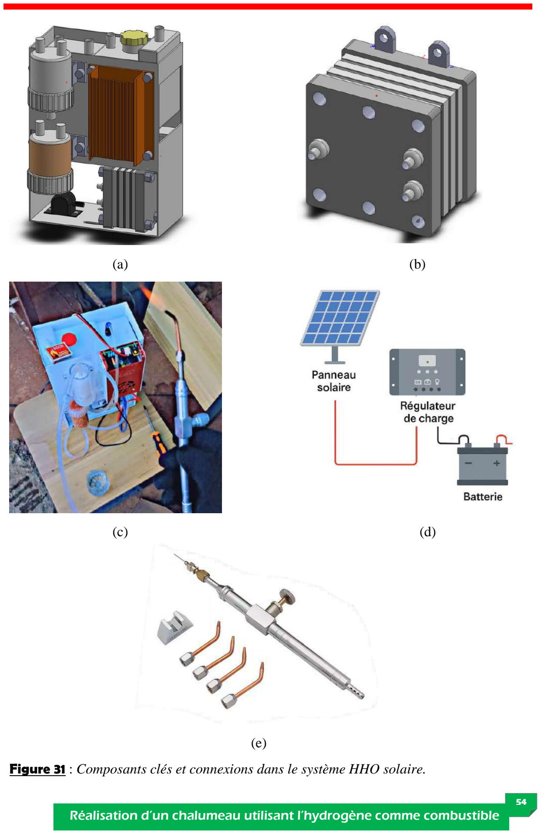
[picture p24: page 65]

54

(a) (b)
(c) (d)

(e)

Figure 31 : Composants clés et connexions dans le système HHO solaire.

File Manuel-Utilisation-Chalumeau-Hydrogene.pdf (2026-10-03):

MANUEL D’UTILISATION DU CHALUMEAU À HYDROGÈNE VERT

INTRODUCTION

Dans le cadre de la première édition du Programme de Fonds d’Appui à l’Innovation Technologique (PFAIT I / UNSTIM), notre attention s’est portée sur le développement de solutions durables autour de l’hydrogène renouvelable en tant que vecteur énergétique propre. Nous avons ainsi conçu un chalumeau innovant, fonctionnant à partir d’hydrogène produit par électrolyse de l’eau. Ce dispositif, fondé sur la production et la combustion d’un gaz propre, se distingue par son caractère renouvelable, non polluant et sécurisé, offrant une alternative viable aux systèmes classiques à base de combustibles fossiles

1. Présentation du dispositif

Ce chalumeau utilise de l’hydrogène produit par électrolyse de l’eau comme combustible. Il est destiné aux opérations de soudage, de brasage et de découpe dans des environnements industriels ou marins. Le dispositif est autonome et alimenté par une source solaire.


Figure 1 : Vue de haut du dispositif complet

2. Composition du système
- Générateur HHO-Drycell (4) pour produire du gaz HHO ;

- Réservoir d’eau (3) pour stocker la solution électrolytique ;
- Cartouche filtrante (6) pour éliminer les impuretés présentes dans l'eau ;
- Séparateur eau-gaz (2) pour séparer l'hydrogène produit de l'eau ;
- Pompe de circulation (5) pour fait circuler l'eau dans le système ;
- Panneau solaire 375W pour capter l’énergie solaire et la convertit en électricité ;
- Batterie LiFePO₄ 24V/10Ah pour stocker l’énergie produite par le panneau solaire ;
- Régulateur de charge 40A pour réguler l’énergie provenant du panneau solaire ;
- Alimentation électrique (1) pour activer le processus d'électrolyse ;
- Bec de chalumeau pour diriger et contrôler la flamme produite ;
- Ensemble de tuyauterie et câblage pour faire le câblage (figure 5) ;


Figure 2 : Vue en perspective du dispositif avec les composants principaux et aussi du drycell.

3.Principe de fonctionnement

L’électricité produite par une batterie alimentée à l’énergie solaire, provoque une réaction électrochimique au niveau du générateur d’hydrogène. Dans la cellule électrolytique, deux électrodes dissocient l’eau en donnant un mélange de gaz

(dihydrogène H2 et dioxygène O2) en présence d’un électrolyte selon la réaction suivante :

2H2 O (l) → 2H2 (g) + O2 (g)

Les deux gaz produits sont collectés dans une bouteille à une certaine pression et température, afin de faire passer le mélange de gaz dans un tuyau muni d’un anti retour de flamme HHO pour des raisons de sécurité. Le bruleur où la combustion de l’hydrogène par le carburant (oxygène) a lieu, produit une flamme de température d’environ 2800C°.

4. Mise en service
1. Remplir le réservoir avec une solution d’eau et KOH ou NaHCO₃, à 6 % de concentration.
2. Connecter le système au panneau solaire et à la batterie.
3. Démarrer la production d’hydrogène.
4. Vérifier la production de gaz et l'absence de fuite.
5. Allumer le chalumeau à l’aide du bec mélangeur.


Figure 3 : Connexion du panneau avec la batterie Figure 4 : Jeu de buses avec le bec

NB : Mesures de sécurité

-Port des gants obligatoires

-Port des lunettes de protection obligatoire


Lunettes de protection | Gants de protection
5. Utilisation
- Utiliser le chalumeau pour chauffer, souder ou découper des tôles fines (jusqu’à 0,8 mm).
- La flamme est concentrée, propre, et peut atteindre une température de 2800°C ou plus.
- Ajuster le débit de gaz à l’aide de la vanne du bec pour obtenir une flamme optimale.
6. Sécurité et entretien
- Ne jamais stocker d’hydrogène : production à la demande uniquement.
- Vérifier régulièrement les tuyaux, raccords et la cellule électrolytique.
- Éviter les étincelles ou flammes nues à proximité lors de la maintenance.
- Porter des équipements de protection (lunettes, gants, etc.).
7. Entretien périodique
- Nettoyer le réservoir et les tuyaux chaque semaine.
- Vérifier l’état des plaques de la drycell chaque mois.
- Remplacer la cartouche filtrante tous les 3 mois si possible.
- Tester régulièrement l'efficacité de la solution électrolytique.
8. Dépannage

-Faible production de gaz : vérifier la concentration de la solution ou l’état de la batterie.

-La pompe n’aspire : vérifier si le filtre à résine est dans la bonne position et si elle est remplie d’eau.

-Pas de flamme : contrôler les connexions et la production de gaz.

-Fuite d’eau ou gaz : resserrer les raccords ou remplacer les tuyaux défectueux.


Figure 5 : Schéma de montage du dispositif

9-Avantages du chalumeau

Le chalumeau à d’innombrables avantages :

- Non polluant : les émissions se limitent à la vapeur d’eau.
- Sécurisé, pas de stockage d’hydrogène.
- A une flamme puissante.
- C’est un équipement portable, autonome en énergie.

CONCLUSION

La réalisation du chalumeau a donné de bons résultats. Néanmoins, pour l’optimisation du système, la poursuite des tests est en cours pour l’amélioration du dispositif.

NB : Il est conseillé de manipuler le dispositif avec soin pour éviter tous dégâts.

Superviseur de l’innovation : Dr Sibiath OSSENI

Porteur de l’innovation : Amour Tamègnon AZONNANKPO

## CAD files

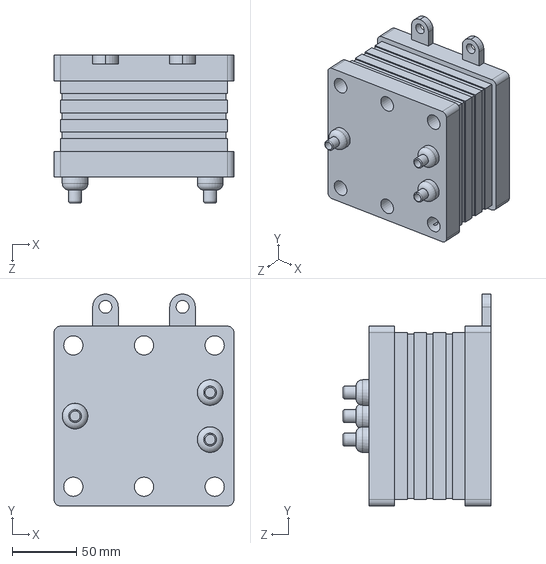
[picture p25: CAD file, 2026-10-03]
Generateur-HHO-Drycell.SLDPRT
140.0 x 165.0 x 115.0 mm

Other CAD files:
Generateur-HHO-Drycell.STL

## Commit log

2026-10-03 Ajout des liens vers la documentation technique
2026-10-03 Ajout du modèle CAO du générateur HHO Drycell
    [Generateur-HHO-Drycell.SLDPRT, Generateur-HHO-Drycell.STL]
